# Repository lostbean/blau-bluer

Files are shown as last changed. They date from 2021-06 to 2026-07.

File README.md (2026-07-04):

# blau-bluer

Mods, tuning, slicer profiles, and PCB-making setup for the Two Trees Bluer 3D
printer.

## Firmware

The Marlin firmware lives in its own repo (with its own nix flake for building):
https://github.com/lostbean/Marlin

## PCB making

The printer is adapted to hold a drill spindle and a laser (mounts in
`mods/`). [`PCB/`](PCB/README.md) documents how to make PCBs with it —
marker-drawn etch resist plus drilled holes — including the pcb2gcode configs
and G-code preambles. A laser-based workflow will be added there later.

The alignment-and-drilling half of this now has a browser app,
**[blau-drill](https://github.com/lostbean/blau_drill)**, that replaces the
manual pcb2gcode + touch-off flow: it fits the fiducials, gates the dangerous
moves behind states you have to pass through, and drives the printer directly
over Web Serial. Try it live at <https://onedgy.com/lab/blau-drill/>; the post
[From Ritual to Software](https://onedgy.com/blog/blau-drill/) explains why it is
built the way it is.

## Contents

- `mods/` — printed mod parts (sources in `.scm`, meshes in `.stl`)
- `tuning/` — calibration patterns, test models, and reference docs
- `PCB/` — guide and configs for making PCBs with the drill mod
- `Cura/` — printer definition, material profiles, and project template
- `ICESL/` — IceSL slicer settings

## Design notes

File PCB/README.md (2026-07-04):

# PCB making

Single-sided PCBs on the modified printer, in three stages:

1. **Paint** the whole copper side with a permanent marker / spray as etch
   resist.
2. **Laser** away the resist over everything that should be etched, leaving
   ink only on the traces (mount: [`mods/laser-holder`](../mods)).
3. **Drill** the holes with the 775-motor spindle (mount:
   [`mods/motor-775-holder`](../mods)).

Then etch off-printer (ferric chloride / iron perclorate) and clean the
remaining ink.

> An earlier workflow drew the traces directly with a pen instead of
> painting + lasering. Those files are still here
> (`pen-drawing.cfg`, `preamble.ngc`, `preamble_for_drill.ngc`) but the laser
> flow below is the current one.

> **Drilling now has a browser app.** The manual alignment + pcb2gcode drill
> flow documented below is superseded for the drill pass by
> **[blau-drill](https://github.com/lostbean/blau_drill)**, which fits the
> fiducials into an affine transform (no touch-off `G92`), forces a dry-run
> before the real run, and streams to the printer over Web Serial. Run it at
> <https://onedgy.com/lab/blau-drill/>. The design rationale is written up in
> the post [From Ritual to Software](https://onedgy.com/blog/blau-drill/). The
> configs below are still the reference for the etch/laser pass and the manual
> fallback.

This folder holds the printer-specific pieces — the pcb2gcode config with
tuned feeds and depths, the G-code preamble that handles touch-off and
zeroing, and a post-processor that adapts pcb2gcode's output to this
printer's Marlin.

| File | Purpose |
| --- | --- |
| `drill.cfg` | pcb2gcode config: Excellon → G-code for the drill pass |
| `preamble_laser_drill.ngc` | Touch-off + `G92` zero on a fiducial (no pen→drill offset) |
| `postamble.ngc` | Returns to home |
| `postprocess_drill.py` | Fixes spindle command for Marlin; emits a dry-run + real-drill pair |
| `pen-drawing.cfg` | (legacy) pen pass — fills inverted Gerber with marker lines |
| `preamble.ngc` | (legacy) pen pass — pause, zero, tip-cleaning triangle |
| `preamble_for_drill.ngc` | (legacy) pen→drill offset preamble |

An example KiCad project made with the pen process lives in
[autofascination/living-blinds/PCB](https://github.com/lostbean/autofascination/tree/master/living-blinds/PCB).

## 1. Design (KiCad)

- Put **fiducials on all four corners** of the board, on the copper side you
  drill from (back copper). Use a copper fiducial footprint (e.g.
  `Fiducial:Fiducial_BCu_Cross_1.5mm_Mask2mm`). Corner fiducials are the
  alignment reference — and unlike the board edge, **they survive etching**,
  so you can still register to them after the outline copper is gone.
- Set the **Drill/Place File Origin** onto one of those corner fiducials
  (not the bare corner). That fiducial becomes the drill-file origin and your
  physical touch-off point.
- Export from **File → Fabrication Outputs → Drill Files** with:
  - Format **Excellon**
  - _Use drill/place file origin_
  - _PTH and NPTH in a single file_ (so you get one `*.drl`, not `-PTH`/`-NPTH`)
  - _Use alternate drill mode for oval holes_
  - **Do not** enable _Mirror Y axis_ — pcb2gcode handles the back-side mirror
    itself (`drill-side=back`). Mirroring here would flip the holes out of the
    reachable frame.

  Sanity check the exported `.drl`: coordinates should be small and centred on
  the chosen fiducial (one axis going negative is fine), not large absolute
  page coordinates (e.g. X135, Y−149) — those mean the drill origin was never
  set.

## 2. Generate G-code (pcb2gcode → post-process)

Point the paths at the top of `drill.cfg` at your exported `.drl`, then run
from that folder. The pcb2gcode in current nixpkgs fails to build against
boost 1.87, so pin the 24.05 channel (it ships a working prebuilt binary):

```bash
nix run github:NixOS/nixpkgs/nixos-24.05#pcb2gcode -- --config drill.cfg
python3 postprocess_drill.py board.drl.gcode --speed 255 --hover 0.2
```

That writes two files:

- `board.dryrun.gcode` — **spindle off**, hovers `--hover` mm above the
  touched-off surface at every hole instead of plunging. Run this first to
  confirm registration without cutting.
- `board.drill.gcode` — the real run: spindle on at full power, plunges to
  `zdrill`.

Preview either at [NCViewer](https://ncviewer.com/).

### Why the post-processor is needed

pcb2gcode (`software=custom`) emits spindle control that does **not** work on
this printer's Marlin: a cosmetic standalone `G00 S<speed>` line plus a bare
`M3`. Marlin needs the duty value **on** the `M3` line (`M3 S255`) or the PWM
is never set ([MarlinFirmware/Marlin#8379](https://github.com/MarlinFirmware/Marlin/issues/8379)).
The spindle now shares the **laser PWM hardware**, so it is driven directly by
G-code rather than an external controller. `postprocess_drill.py` rewrites the
spindle command, builds the dry-run variant, and can set the touch-off `G92`
to a fiducial position (`--fiducial`, see below).

Values tuned on this printer — change with care:

- `zdrill=-2.5` (through the board into the sacrificial layer),
  `drill-feed=200`, `zsafe=5`, `zchange=30` (lift for bit changes).
- `software=custom` + `nog81=true` because Marlin has no canned drill cycles.
- `drill-speed=255` = full PWM duty (Marlin `CUTTER_POWER_UNIT=PWM255`).

## 3. Align to the fiducial

The drill file's origin is on a corner fiducial, so the fiducial corresponds
to the origin of the G-code frame. In the simple case (origin fiducial maps
to G-code `(0,0)`), the preamble's plain `G92 X0 Y0 Z0` at touch-off is
correct, and holes on the far side may sit at slightly negative coordinates —
the machine accommodates that after the local `G92`.

If the fiducial you align to maps to a non-zero corner of the hole envelope
(e.g. because of the back-side X mirror), let the post-processor read that
corner from the G-code and bake it into the preamble's `G92` — no CAD lookup:

```bash
python3 postprocess_drill.py board.drl.gcode --fiducial bl   # bl|br|tl|tr
```

`--fiducial bl` sets `G92 X<minX> Y<minY> Z0` (the min-X/min-Y hole-envelope
corner), so touching off there tells Marlin where the fiducial is and every
hole lands relative to it. Pick the corner that the back-side mirror maps your
chosen fiducial to (for a KiCad lower-right fiducial drilled from the back,
that is `bl`). Verify in the post-processor's printed hole-envelope numbers.

## 4. Drill

The generated files include pauses (`M0`) — one at touch-off, and one per bit
size change.

1. Upload `board.dryrun.gcode` and `board.drill.gcode` to the printer
   (OctoPrint recommended).
2. Mount the drill bit. At the first pause, position the bit over the corner
   fiducial and lower Z until it just touches.

   **Energize the motors before the final adjustment.** When the steppers are
   de-energized (idle) and then re-engage, they snap to the nearest full step
   and jump 1–2 mm — enough to ruin alignment. So make the _final_ X/Y nudge
   with the motors already on, using the printer's jog/move control, rather
   than pushing the head by hand and letting it re-engage. Jog each axis a
   little first to make sure every motor is holding, then fine-tune onto the
   fiducial.

3. Resume. The preamble runs `G92` to set the fiducial as the zero reference.
4. **Run the dry run first** (`board.dryrun.gcode`). The bit hovers
   `--hover` mm above every hole so you can confirm the pattern lines up with
   the board. There are still per-bit pauses — just resume through them; you
   are not changing bits during a dry run.
5. If registration is good, run `board.drill.gcode`. It drills every hole,
   pausing at each bit-diameter change so you can swap the bit. **Do not move
   X/Y at the bit-change pauses** — only swap the bit and re-touch Z.

## 5. Etch

Etching happens off-printer: the remaining marker ink is the resist, so etch
the board (ferric chloride / iron perclorate) and clean off the ink
afterwards.

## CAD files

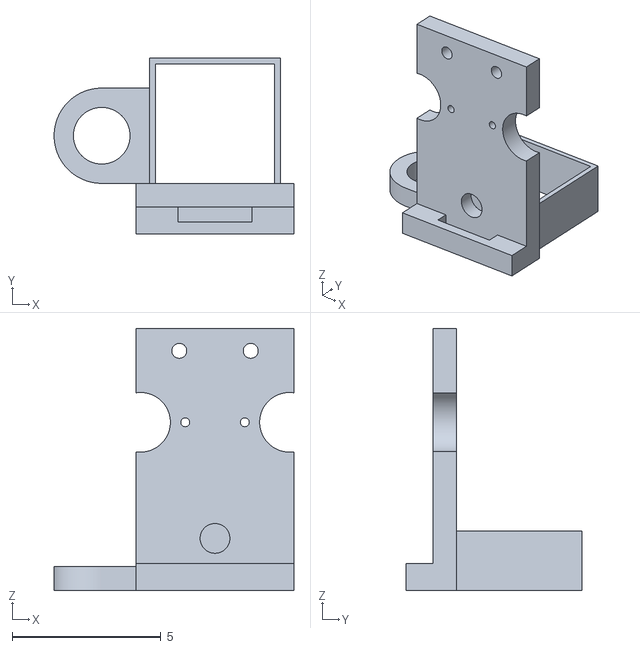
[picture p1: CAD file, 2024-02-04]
mods/laser-holder.stl
8.06 x 5.91 x 8.80

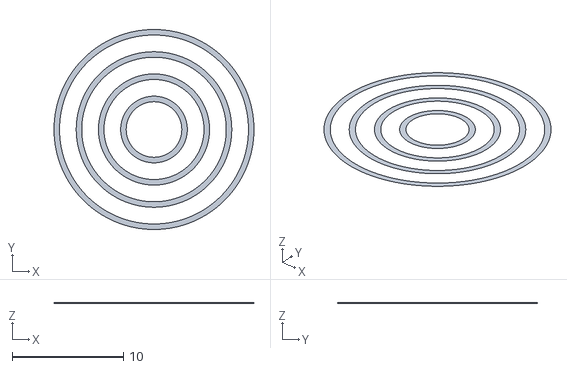
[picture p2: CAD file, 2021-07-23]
tuning/models/bed_level_circles.stl
18.0 x 18.0 x 0.02

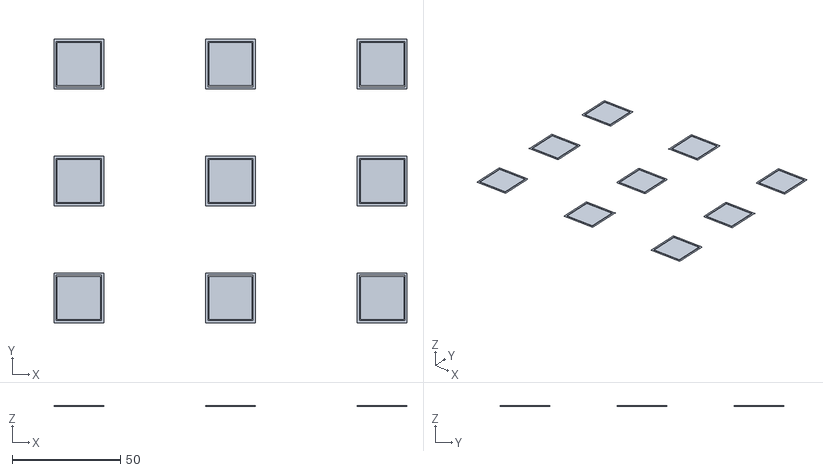
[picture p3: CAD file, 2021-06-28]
tuning/models/Bed_Leveling_Calibration_Test_Object_Parametric/Bed_Levelling.stl
163.0 x 131.0 x 0.1

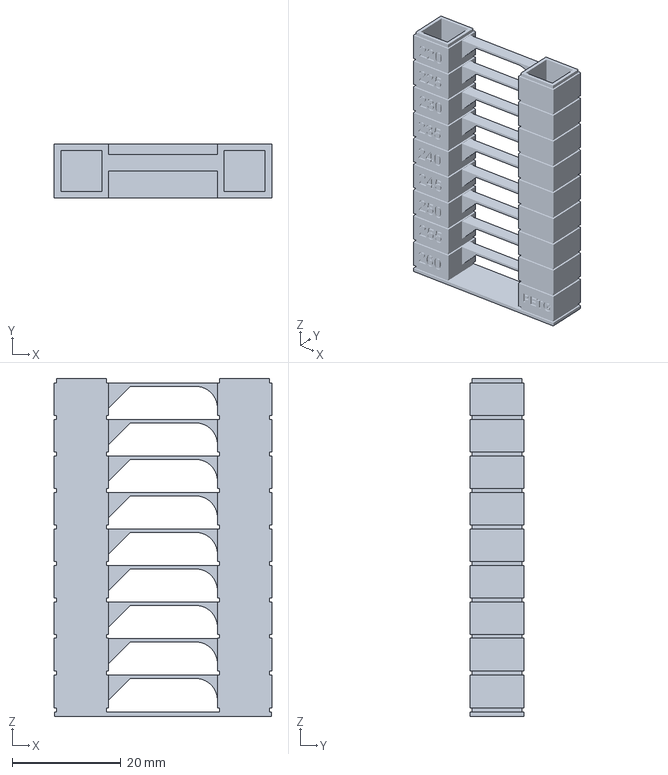
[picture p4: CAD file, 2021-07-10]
tuning/models/TWOTB_220-260PETG_Temp_Tower_.3mf
40.0 x 10.0 x 62.2 mm

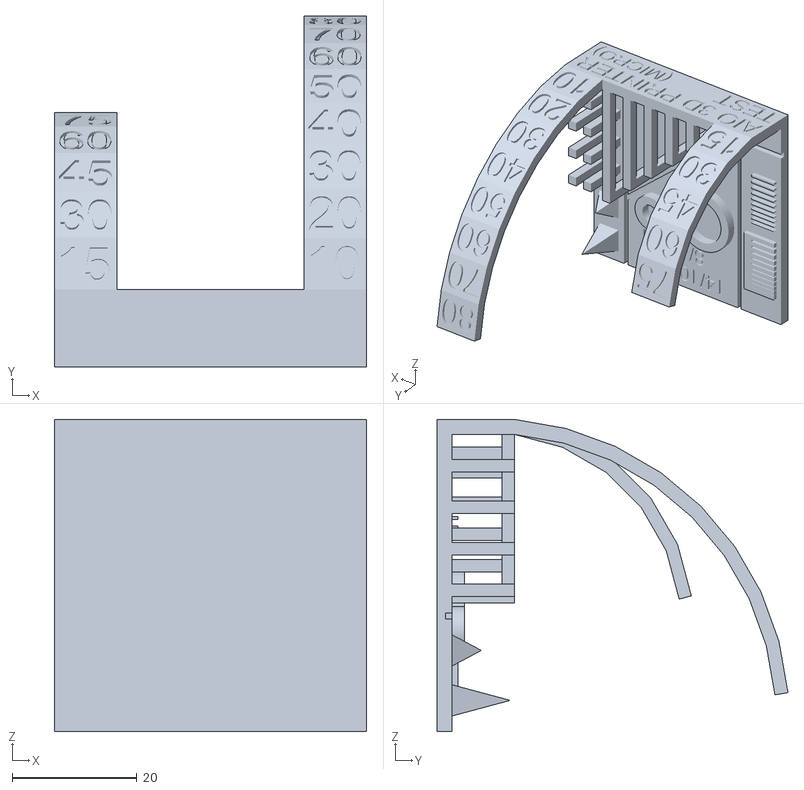
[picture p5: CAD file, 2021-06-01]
tuning/models/All_In_One_3D_printer_test_micro.stl
50.0 x 56.2 x 50.0

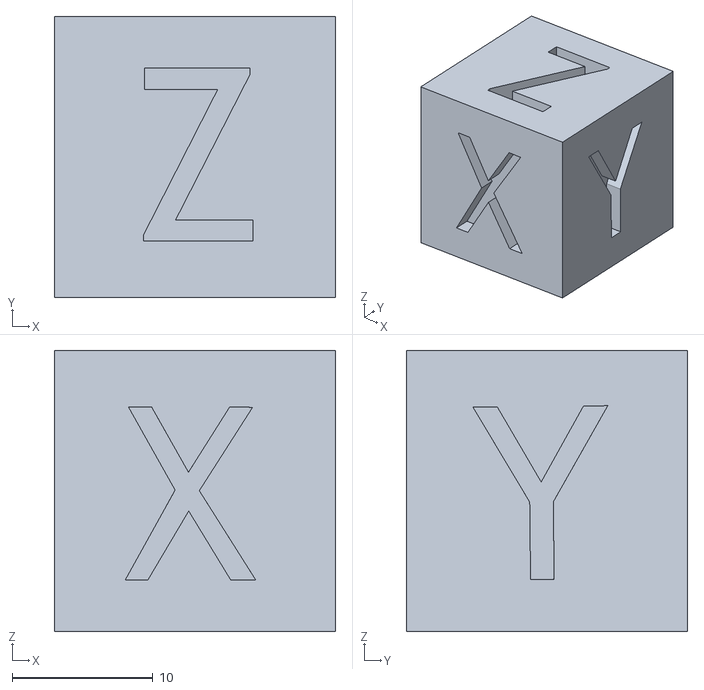
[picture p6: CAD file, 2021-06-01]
tuning/models/xyzCalibration_cube.stl
20.0 x 20.0 x 20.0

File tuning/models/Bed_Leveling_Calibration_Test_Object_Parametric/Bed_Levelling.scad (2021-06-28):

/**
 * Print designed to check that you bed is level
 *
 * print four small squares in each corner to ensure even print quality and good adhesion.
 */

// Define your printers printable area
// If you are using Sprinter firmware then these come directly from configuration.h

X_MAX_LENGTH = 210;
Y_MAX_LENGTH = 178;

THICKNESS = 0.1; //Square / outline thickness
SIZE = 20; //Square width / height
GAP = 0.5; //Width of border between square and parameter
OUTLINE_WIDTH = 1; //Width of parameter around square
OFFSET = 25; //Offset from limits in each axis

translate([OFFSET, OFFSET, 0]) square(); //Top Left
translate([(X_MAX_LENGTH / 2) - (SIZE / 2), OFFSET, 0]) square(); //Top Middle
translate([X_MAX_LENGTH - OFFSET - SIZE, OFFSET, 0]) square(); //Top Right

translate([OFFSET, (Y_MAX_LENGTH / 2) - (SIZE / 2), 0]) square(); //Middle Left
translate([(X_MAX_LENGTH / 2) - (SIZE / 2), (Y_MAX_LENGTH / 2) - (SIZE / 2), 0]) square(); //Middle Middle
translate([X_MAX_LENGTH - OFFSET - SIZE, (Y_MAX_LENGTH / 2) - (SIZE / 2), 0]) square(); //Middle Right

translate([OFFSET, Y_MAX_LENGTH - OFFSET - SIZE, 0]) square(); //Bottom Left
translate([(X_MAX_LENGTH / 2) - (SIZE / 2), Y_MAX_LENGTH - OFFSET - SIZE, 0]) square(); //Bottom Middle
translate([X_MAX_LENGTH - OFFSET - SIZE, Y_MAX_LENGTH - OFFSET - SIZE, 0]) square(); //Bottom Right

module square() {
	//Center square
	translate([
				OUTLINE_WIDTH + GAP,
				OUTLINE_WIDTH + GAP,
				0
			])
		cube([SIZE, SIZE, THICKNESS]);

	//Parameter
	difference() {
		//Outer square
		cube([
				SIZE + (2 * (GAP + OUTLINE_WIDTH)),
				SIZE + (2 * (GAP + OUTLINE_WIDTH)),
				THICKNESS
			]);

		//Inner square
		translate([OUTLINE_WIDTH, OUTLINE_WIDTH, -5])
			cube([SIZE + (2 * GAP), SIZE + (2 * GAP), 10]);
	}
}

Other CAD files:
Cura/project-template/PETG-3DFila.3mf

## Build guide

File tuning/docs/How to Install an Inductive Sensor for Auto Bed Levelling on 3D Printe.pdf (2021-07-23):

store.ideagen.tech

## How to Install an Inductive Sensor for Auto Bed Levelling on 3D Printe

ideagen3D

8-10 minutes

Just acquired an Inductive Sensor for auto bed levelling? It's a good alternative to dynamic probe-style ABLs:

1. It's cheaper.
2. It has no moving parts - never worry about the probe drooping down and crashing into your prints.
3. However, it's only compatible with metallic and (very-thin) plastic beds. On the bright side, the best consumer 3D printer bed currently (in our opinion) happens to be metallic!
4. Instructions and discussions around this has also been scarce and/or abstract, but we're here to change that!

This is a guide focused on the Ender 3 V2, and our 12mm NPN Inductive Sensor. However, instructions should
be easily transferable to other printers and similar probes since we are not using any niche ABL-specific hardware ports! Just look up the disassembly process on your own printer.

### 3D Printed Mounts

Before starting, you should have a printed mount on hand. ideagen3D has designed mounts for the Ender 3/Pro, Ender 3 V2, and Sapphire Plus.

Ender 3/Pro

Ender 3 V2

Sapphire Plus

### Physical Installation

1. Before starting the installation, please ensure that the bed corners as level (as much as possible) with the springs. Take care not to accidentally rotate the bed levelling springs during this process.
2. Turn off the printer and disconnect the PSU.
3. Push the Bed to the back, and unscrew this bolt.

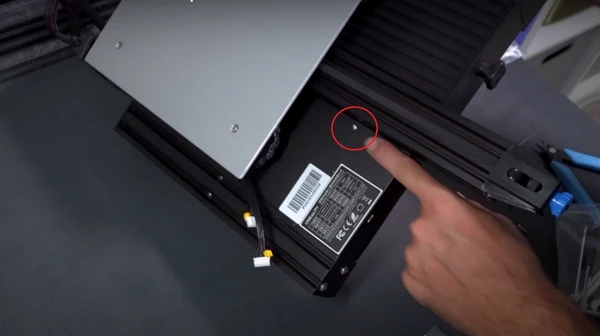
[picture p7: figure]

4. Remove all attachments (e.g.filament spool holder) from the top of the printer, turn the printer upside down and lean it against something.
5. Unscrew these 3 bolts.

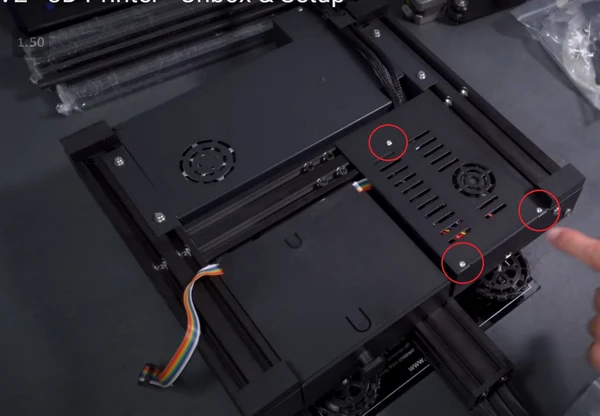
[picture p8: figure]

6. Once inside, disconnect the Zmin stop (check the yellow tag). If you have an upgraded board (e.g. MKS or SKR), it might be preferable to use one of the unused sockets, such as Filament Runout Sensor 2.

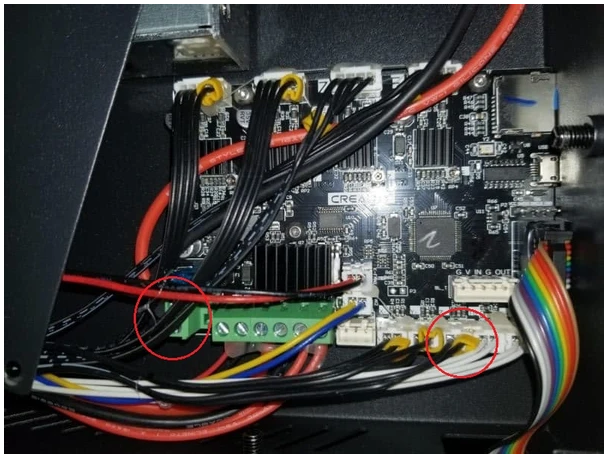
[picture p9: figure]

7. Insert the pre-terminated (black and blue wires) in its place. Polarity does not matter. A dab of hot glue or blue tack may be helpful to hold it in place as this terminal is not self-locking.
8. Now, we need to splice power (12v or 24v) and ground from somewhere. If your board has spare sockets, go ahead and use those. However, the Ender 3 V2 does not, so we will splice into the main 24v power coming in from the PSU.

Loosen the thick red wire from the PSU (red circle on the left, obscured by the black wires on top), and wrap or solder the unterminated (brown) wire around it. It may be helpful to strip a little more of the red jacket so there’s more length to intertwine, but remember to heatshrink/tape back that area to avoid shorting against the metal enclosure.

9. When the wires are in good contact, insert them back into the original hole and tighten back down.
10. Manage the wires to go out the back with the main loom, some zip ties may be helpful.
11. Install the mounting bracket with the provided screws on the unused threads.

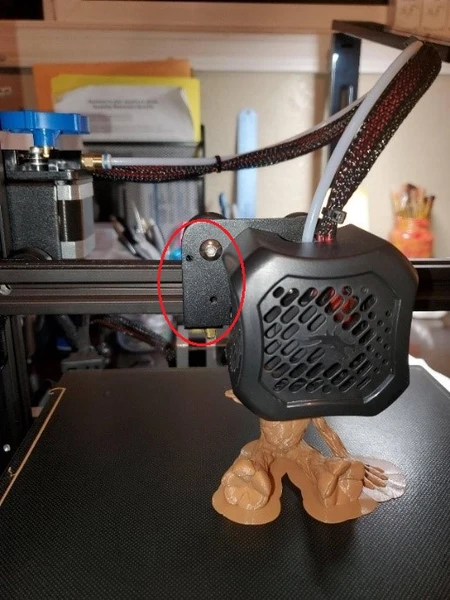
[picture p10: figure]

12. Loosen the nuts on the sensor, and remove the washers. Then, with one nut in place, drop the sensor into the mounting bracket’s hole.

13. The bottom of the sensor should be ~3mm above the nozzle. Adjust this with the top nut, then secure by counter-locking with the other nut from the bottom. We will fine-tune this later.
14. Do some further cable management if necessary.

### Firmware

Here, we will guide you through modifying your firmware to enable support. This guide assumes basic familiarity with modifying and flashing marlin-based firmware. If you are not already familiar with Firmware modifications and flashing, please watch these videos by Michael from Teaching Tech (1, 2), as well as at least a couple videos focused on your specific 3D printer model before proceeding.

ideagen3D customers can contact us for a pre-compiled firmware for printers we carry, assuming no other modifications.

Remember to make a back-up (or a clean base from the manufacturer's website). We are not responsible for any faults or damage caused by improper firmware.

1. Start with a base of Marlin that has been validated to work. Check your printer, mainboard, BAUD rate, etc... are correctly designated.

2. Check/Change these lines in Configuration.h
1. Search "define Z_MIN_PROBE_ENDSTOP_INVERTING" around line 658, and set value to true. This is for NPN probes (that we carry). Leave as false if you have a PNP probe from elsewhere.
2. Search "Z Probe Options", around line 832.
If you have replaced the Z-min probe (as suggested for Ender 3 above), uncomment
#define z_min_probe_uses_z_min_endstop_pin and

#define use_probe_for_z_homing

If you have added the probe into another socket (suggested if you are using an upgrade board, e.g. MKS or SKR), uncomment #define z_min_probe_pin XXX and replace XXX with your selected socket. Consult your mainboard's pinout diagram for this.

3. Search "define FIX_MOUNTED_PROBE" around line 882, and uncomment it.
4. Search "define NOZZLE_TO_PROBE_OFFSET" around line 996, and change your nozzle offset values accordingly (shown here is for the Ender 3 V2 with our printed mount).
#define NOZZLE_TO_PROBE_OFFSET { -43, -1, 0 }

5. Search "define MULTIPLE_PROBING 2" around line 1006

(optional, recommended),
uncomment and verify value of
#define MULTIPLE_PROBING 2

6. And right below, around line 1065, verify these values
#define Z_CLEARANCE_DEPLOY_PROBE 0 // Z Clearance for Deploy/Stow

#define Z_CLEARANCE_BETWEEN_PROBES 10 // Z Clearance between probe points

#define Z_CLEARANCE_MULTI_PROBE 3 // Z Clearance between multiple probes

#define Z_AFTER_PROBING 5 // Z position after probing is done #define Z_PROBE_LOW_POINT -1 // Farthest distance below the trigger-point to go before stopping

// For M851 give a range for adjusting the Z probe offset
#define Z_PROBE_OFFSET_RANGE_MIN -10 #define Z_PROBE_OFFSET_RANGE_MAX 10

// Enable the M48 repeatability test to test probe accuracy #define Z_MIN_PROBE_REPEATABILITY_TEST

7. Search "define AUTO_BED_LEVELING_BILINEAR" around line 1319, and uncomment it.

8. And right below, around line 1328, uncomment
#define RESTORE_LEVELING_AFTER_G28

9. Search for "define GRID_MAX_POINTS_X" around line 1380 Verify that it is uncommented, and set it to your preferred value. As a general rule of thumb, you want one point for every 60mm bed size, and it has to be an odd number so the center gets probed. This translates to 3 for the Ender 3, and 5 for Sapphire Plus.
10. All done! Go ahead and re-compile and flash.

### Calibration

1. Turn on the printer, test the sensor with a metal object (screwdriver, scraper, etc). The LED should be OFF when not detecting anything, and ON when it detects metal. Otherwise stop here and revise your firmware, particularly
"define Z_MIN_PROBE_ENDSTOP_INVERTING".
2. Move the Nozzle/Inductor to approximately above the bed spring at the the front-right corner of the bed (nearest to LCD screen), either manually via Disable Steppers or through movements in the LCD.
3. Leave a piece of paper on the bed at this.
4. Turn on preheating to PLA temperatures (200 nozzle, 60 bed), and use the menu to decrease Z axis. Use finer resolutions as you approach the bottom, because you want to manually stop the very instant you hear the tactile “click” from the z-stop. The Z-stop is no longer electronically connected to the printer, and hence is not functional.
5. Double check with the paper that the nozzle is approximately levelled on the bed (not too far, not physically colliding either, dragging the paper in swift motions should feel some “catch”).
6. Remove the piece of paper.
7. Carefully adjust the mount height of the inductive probe until it the LED *just* turns on. Be careful not to accidentally change Z height of the gantry during these adjustments (by leaning on it etc).

### Slicer G-Code modification

There are 2 options here

1. Level the bed and generate the mesh manually, once, through the LCD, then load it up every time a print starts
2. Fresh levelling and mesh on every print. This takes slightly more time but gives better leveling, especially if the bed is moved between prints.

We prefer option 2 - fresh levelling before every print. Either way, first locate the G-Code settings in CURA.

1. At the top left corner, select Settings > Printer > Manage Printers > Machine Settings
2. On the bottom left, there is Start G-Code
3. Look for the G28 line (should be around halfway).

Click here for Option 1 (level once)

add

M420 S1 Z2 ;Enable ABL using saved mesh

after G28 (on the same line)

Click here for Option 2 (level before every print)

add

G29 ;Fresh ABL

after G28 (on the same line)

New generated G-Code from now on should have ABL before printing. This will not affect old G-Code, such as Creality’s provided test prints or pre-sliced G-Codes downloaded from Thingiverse.

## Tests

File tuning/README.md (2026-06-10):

# Bed Level

==========

## Gross level adjustment

First bed level adjustment should be using a piece of paper and the "Level Bed Corners" option on Marlin. This option will bring the nozzle on top of each spring/screew support.

- Before starting, make sure the nozzle doesn't hit the plate when at Z=0.0 by over-compressing the springs (using the knobs under the plate).
- Start the sequence and on each corner put the paper under the nozzle and, while releasing the srping, keep moving the paper in circular motion.
- Stop when the paper starts to get stuck (very suddle feeling) between the plate and the nozzle.
- Repeat the round at least two more times

## Fine mesh level adjustment

This is a fine refinement of the bed level adjustment. It maps the Z variation at different points over the bed creating a Z variation surface to compesate for flatness distortions on the plate.
This process is similar to the process above using the paper but instaed of adjusting the springs, the nozzle will move a high Z possition (normally 0.2mm) and a menu will allow the to adjust the Z position.

After the procedure, store the settings.

## Z offset adjustment

After the bed level adjustment, the Z offset (the distance between the nozzle and the plate) has also to be adjusted. The correct height of the first layer depends of correct Z offset. The Z offset can be configured on the "Bed Z" option.
A GCODE pattern with 5 single layer squares (four on corners and one on the center) is used to validate the correct Z offset.

## References

https://marlinfw.org/docs/gcode/G029-mbl.html
https://teachingtechyt.github.io/calibration.html#firstlayer
https://help.prusa3d.com/en/article/first-layer-calibration_112364/

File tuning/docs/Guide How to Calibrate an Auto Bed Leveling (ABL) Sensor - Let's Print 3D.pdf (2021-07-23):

# Guide: How to Calibrate an Auto Bed Leveling (ABL) Sensor

Several months ago I wrote an in-depth article on How to Setup Auto Bed Leveling which covered the entire process from start to =nish… at least almost. This was my =rst time using auto bed leveling and I was still testing out various methods to calibrate the sensor, where I decided to leave this for a separate guide. At that point, none of the instructions I had found worked out and print jobs would embed plastic in to the build surface, needing to be replaced several times in the process.

As I was getting tired of buying more Build Tak stickers every other week, I went looking once again and stumbled across a video from 3D Maker Noob that seemed promising. Rather than try to adjust the sensor’s position by hand, he used a series of g-code commands to calibrate it with ease. Go =gure, it took all of 5 minutes and my auto bed leveling sensor was near perfect.

Contents
1. Software
2. Calibrate
Steps
3. Start Script
4. Final Thoughts

Compile Marlin Firmware
without VSCode

How to
Install
Klipper on
the Creality
Cloud WiFi
Box

How to
Install the
Gulfcoast
Robotics
Heated Bed
(Ender 3 / 5)
Home | Posts | About
| | Contact
Home ! | Guides ! | Guide: How to Calibrate an Auto Bed Leveling (ABL) Sensor

October 26, 2018

RECENT POSTS

Most of this guide will just reiterate the information he provides in the video, but several personal observations have been added as well. Once you understand it, auto bed leveling makes perfect sense, but most of the resources found online are either needlessly complicated or just plain wrong.

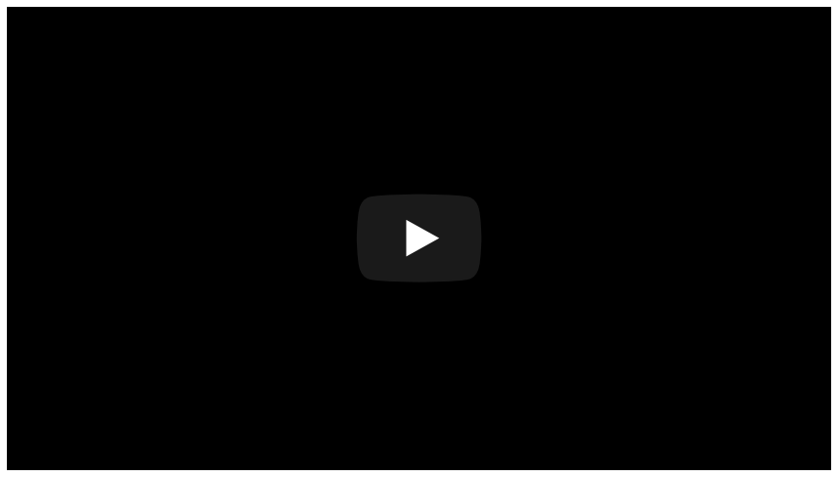
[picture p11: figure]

# Software

Before we can get started, we =rst need to grab some software that can communicate with the 3D Printer over USB. Most slicers have this feature built-in, but Cura seems to be the rare exception that lacks direct machine commands (despite otherwise being a complete printing solution). There are however several other tools I have linked below that will work just =ne for our needs, where I would suggest Pronterface based on the simple, easy to use interface.

Pronterface
Repetier Host

As a third option, Simplify3D ($149) is exceptional software and my preferred slicer software of choice. It is however quite expensive and not worth the price tag for the average person, so unless you already own it, one of the free solutions above will be more than capable of getting the job done.

The 8 Best
Extruder
Upgrades
for Creality
Ender 3
[2021]

Calibrating Z-Offset With A BLTouch Bed Lev…

# Calibrate Steps

Go ahead and connect the 3D Printer to your computer using a USB cable and power it on. Start up Pronterface (or whatever software you decide to use) and connect it to the machine. The Baud Rate will likely be set to the default of 115200 and the COM port will appear when the 3D Printer is connected, such as COM3.

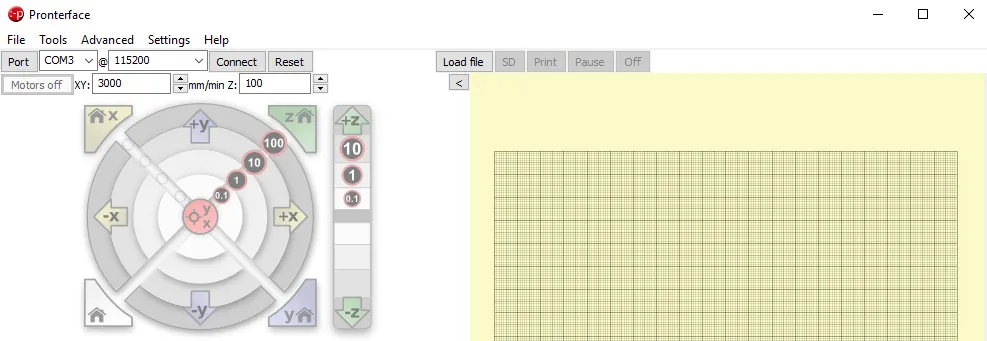
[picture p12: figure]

Now our goal here is to =nd and set the proper Z-Offset for our nozzle, based on the position of the ABL sensor and where it triggers. The Z-Offset is an adjusted value, which raises or lowers the nozzle from the actual home position. So if we run “Auto Home” and the current nozzle position is at 0, a Z-Offset of -0.5mm would bring it closer to the bed.

It’s important to note that the Z-Offset value is not used when the printer auto homes (G28 command) or probes (G29 command) the bed, only during an actual print. This wasn’t documented anywhere and caused quite a bit of initial confusion on my part.

Since there may already be a pre-existing z-offset con=gured in the =rmware or EEPROM, we will start by clearing out any current values and reset the offset to 0.00.

G28 Home the nozzle
M851 Z0 Set the z-offset to zero
M500 Store the settings to EEPROM

! Step 1: Clear the Z-Offset

M501 Load the settings from EEPROM
M851 Echo the current z-offset value, make sure this reports Z0

When the Auto Bed Leveling (ABL) sensor is triggered, the =rmware will raise the nozzle up by several millimeters. Since we want to work from the actual 0 z-offset, we need to re-position it at the point the sensor was triggered. To do this, we will use G1 F60 Z0, where G1 is the move command, F60 is the travel speed, and Z0 is where we are moving to.

G28 Z Home the nozzle on the Z axis
G1 F60 Z0 Move the nozzle down to the actual 0 offset

Just like we are used to with manual bed leveling, go ahead and insert a piece of paper under the nozzle to test the distance. Using the movement controls in the software, start lowering the nozzle towards the build plate in increments of -0.1mm, until there is a slight drag on the paper when sliding it underneath. We will temporarily disable the software endstops, where that will allow us to go in to negative values on the Z axis while we calibrate the proper offset.
Once you are satis=ed with the distance between the nozzle and the bed, make a note of the z-offset on the 3D Printer’s LCD screen, which should look something like “Z-0.5”. Now add the thickness of the paper you used to this value and that is your actual z-offset.

Note: A normal sheet of paper has an average thickness of 0.08mm. If your LCD screen reads Z-0.5, we would con=gure this as Z-0.58.

! Step 2: Move to Actual Z-Offset

! Step 3: Calibrate Z-Offset

M211 S0 Turn OFF the Software Endstops M851 Z-0.58 Set the z-offset value
M211 S1 Turn ON the Software Endstops M500 Store the settings to EEPROM M501 Load the settings from EEPROM

# Start Script

Since we want the 3D Printer to use the auto bed leveling sensor and probe the surface before each print, we need to tell it to do so via the Start script. This is a list of G-code
commands that it executes in order before the print can start. Open your preferred slicer software, locate the Start script and add the G29 probe command to it.

Cura: To access the Start script g-code in Cura, go to the Settings menu -> Printer -> Manage Printers. Select the desired printer in the list and click the Machine Settings button next to it. You will =nd the “Start G-Code” section in the bottom left.

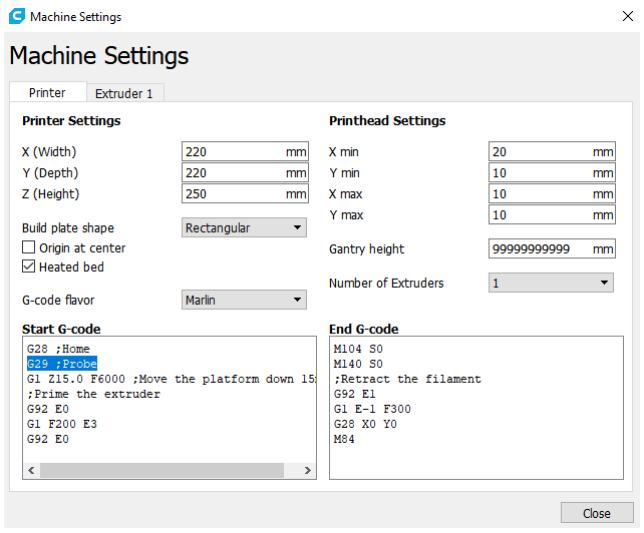
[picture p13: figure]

Simplify3D: To access the Start script in Simplify3D, open the Process Settings -> Scripts tab -> Starting script tab.

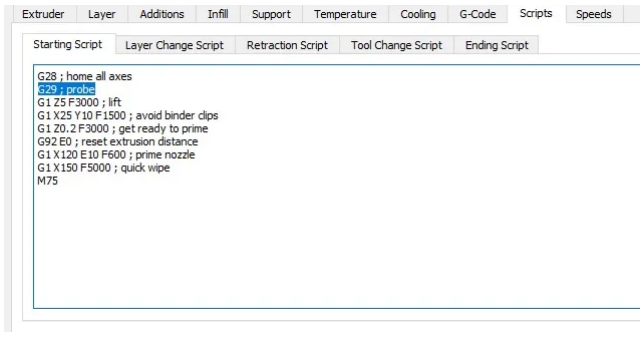
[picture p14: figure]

# Final Thoughts

As I am of the mindset “why =x what isn’t broken”, auto bed leveling always seemed like a solution for a problem that didn’t exist. Sure, it takes a few minutes to level the bed by hand, but I didn’t exactly understand what this feature was capable of. Until it was properly con=gured, it seemed to be a hindrance more so than anything, turning a simple process in to something complex.

Once it was setup and I eventually =gured out how to calibrate the sensor, the bene=ts became much more apparent and it was a luxury I came to appreciate. While it of course reduces the frequency in which leveling is required, the real upside was the fact that it maps out the build surface when probing. In cases where the bed isn’t perfectly iat, it will use the generated mesh data to adapt and work around imperfections in the plate… something that manual bed leveling simply cannot do.

" PREVIOUS ARTICLE

## Guide: How to Install the Micro Swiss All Metal Hotend (Ender-3)

NEXT ARTICLE !

## Guide: How to Upgrade the Extruder (Ender-3)

# 8 thoughts on “Guide: How to Calibrate an Auto Bed Leveling (ABL) Sensor”

Dear Brett,

I have been suffering for days after I upgraded my 3D printer with 3D touch sensor, thanks to your excellent guide, I was able to properly con=gure it =nally! (after tens of failed prints and many frustrations ). I appreciate your kind efforts in making this guide and sharing it with the rest of the planet.
Salute,
IC

# REPLY

Ihsan Cicek
December 14, 2020 at 8:16 pm

Hi Ihsan,

That’s awesome! I’m glad to hear this helped get it sorted out.

You’re de=nitely not the only one that has suffered through this. Despite being relatively knowledgeable with =rmware, con=guring and calibrating bed leveling sensors left me extremely confused. It wasn’t well documented and everything I found online seemed to be wrong. It took a lot of experimenting to =gure out what worked, but that video I linked from Breaks n Makes was a great starting point.

-Brett

# REPLY

Same as Ishan here. Thank you so much Brett !
After a =rmware update (where I just changed the MAX number of points for the ABL mesh), impossible for me to set the Z offset correctly again. I spent my entire evening yesterday trying to =x this, driving me nuts.
In step 3, why do you switch off the Software Endstops (M211) before running the M851 command ?
I understand that M211 is used to prevent motion outside a prede=ned boundary, but M851 is just changing a value in memory, it does not actually move the head. Does the M211 command here really do something ?
-Michel

Brett
December 14, 2020 at 11:24 pm

Michel Saint-Ghislain
January 3, 2021 at 7:05 am

# REPLY

Hi Michael,

I wrote this guide a couple years ago, mostly as a reminder for myself when I have to do it again 🙂 The steps aren’t so fresh on my mind anymore, but the way I wrote that section is a tad confusing.

For the second step “Set the Z-Offset value”, I think this was really meant to encompass all of the instructions above. It’s not just 1) turn off endstop 2) set the value and 3) turn endstop back on. The second step should also be =guring out the desired value as described in the preceding paragraphs. I will look at rewriting that part to make it more clear.

-Brett

# REPLY

I found your guide through a google search, and after checking further your website, I noticed that this guide is not to be seen in the “Posts” section. Maybe is it on purpose as it is older ? Anyway just wanted to let you know.
-Michel

# REPLY

Brett
January 3, 2021 at 5:53 pm

Michel Saint-Ghislain
January 3, 2021 at 8:38 pm

Thank you for this fantastic article.
One question: are you adding these commands to your start-up script, or storing them in the EEPROM from pronterface? My issue is that it doesn’t care at all what is in EEPROM, slices from cura 4.8 never take the stored zaxis settings into account.

Is it calling the eeprom settings after the auto bed leveling commands?

G28 Home the nozzle
M851 Z0 Set the z-offset to zero
M500 Store the settings to EEPROM
M501 Load the settings from EEPROM
M851 Echo the current z-offset value, make sure this reports Z0

# REPLY

Hi Kent,

What control board do you have running on your 3D Printer? Certain models like the SKR Mini E3 V1.2 did not have an on-board EEPROM, where that could potentially explain the issue.

As for those speci=c steps, they are being entered into the live console from Pronterface, where that’s the equivalent of just sending commands directly to the 3D Printer. G28 homes it, then we clear the existing Z offset (just in case to be on the safe side), followed by storing/reloading EEPROM

Kent
March 11, 2021 at 3:54 am

Brett
March 11, 2021 at 8:19 pm to make sure the changes were in fact saved.

-Brett

# REPLY

Brett, Wow man thank you. I tried to get the BL Touch up and running so many times manually. I could not get it to work. Thanks to your guide i just printed the best print yet with a brim that was so consistent that I want to frame it!

# REPLY

# Leave a Reply

Copyright © 2021 Let's Print 3D. All rights reserved. Theme: Cenote by ThemeGrill. Powered by WordPress.

Jeff t jackson
July 6, 2021 at 8:25 pm

Your email address will not be published. Required =elds are marked *

COMMENT

NAME * | EMAIL *

WEBSITE

SAVE MY NAME, EMAIL, AND WEBSITE IN THIS BROWSER FOR THE NEXT TIME I COMMENT.

POST COMMENT

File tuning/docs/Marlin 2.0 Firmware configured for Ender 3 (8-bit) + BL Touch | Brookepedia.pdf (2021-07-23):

# Brookepedia (/p/en)

by Daniel Brooke Peig

## Marlin 2.0 Firmware con1gured for Ender 3 (8-bit) + BL Touch

This is the vanilla version of Marlin Firmware 2.x pre-con2gured for Creality Ender 3 printers with original or generic BL Touch sensors. The standard con2guration 2le from Marlin distribution was carefully reviewed to include the latest Ender 3 speci2c settings from the oAcial Creality 2rmware and from Antclabs.

Please note that this is not the version I recommend for 8-bit boards like the one used in the Ender 3. The most stable and feature rich version of the 2rmware for this architecture is the 1.1.9 that I made available in another article (/p/en/node/136). Marlin 2.x is aimed to a new generation of boards using 32-bit processors, the built in libraries are bigger and there is less space left for features. Anyway, if you want to try this you can be sure I did the best I could to con2gure it properly and 2t the maximum amount of features possible. It was downloaded and installed more than 10000 times and I believe most of the users will 2nd no problems with it.

### Features

OAcial "vanilla "Marlin 2rmware with all hardware settings from Creality latest oAcial 2rmware.

1 year ago | By Daniel (/p/en/user/1) | | | 206 comments
English (https://www.danbp.org/p/en) | Português (https://www.danbp.org/p/pt-br/node)

!

Home " | Engineering (/p/index.php/en/engineering) | Computing (/p/index.php/en/it)
Outdoors (/p/index.php/en/outdoors) | Reviews (/p/index.php/en/reviews)

About (/p/index.php/en/about)

(/p/en)

The maximum amount of Marlin features that I was able to 2t in the small 128KB memory. BLTouch original/generic versions enabled by default. Compatible with BLTouch versions from 1.0 up to 3.x
No need to remove any capacitors from the board
Installs from the PlatformIO IDE that runs in several operating systems
Source code modi2ed to prevent releasing the BLTouch sensor during "beep" events triggered by LCD menus
Thermal runway protection enabled
Does not reset the bed level settings after the G28 (Home) command
Custom menu with maintenance mode, emergency mode and full auto bed leveling sequence (warmup, wait, home, level and then save settings)
Ultra-precise bilinerar bed leveling algorithm with 25 probing points, 3 slow probes per point (takes about 10 minutes to complete)
Run and toggle the bed level and BLTouch tools from LCD menus
Tuned PIDs for faster heating
M503 enabled (reports all printer settings)
Baby steps enabled and con2gured for the stepper driver "Magic Numbers"
Fully compatible with OctoPrint
All changes from the original Marlin con2g 2le were marked with the comment tag "Customized DBP"
Due memory size limitations, the power resume function was disabled as well as the arc support
LCD menus were changed to "slim mode" to save memory space
Optional compiled 2les ready to upload to the board (no con2guration, no compilation, no installation of any tools):
Creality standard board
Creality upgraded boards with TMC silent drivers (like the 1.1.5)

### Note about the bed leveling strategy

There are two ways to perform the automatic bed leveling, the 2rst is before every print and the second is only when necessary. Based on my experience with the Ender 3, it's better to do an extremely precise (slower) bed leveling when necessary than a simpler one before every print. This 2rmware con2guration redects this choice.

If you want to do quick/imprecise bed leveling before every print you will need to recon2gure the 2rmware.

### Requirements

BLTouch installed on pin 27
Z stop switch removed (it can block the Z axis movement)

IMPORTANT! BLTouch tip height must be adjusted according to the oAcial instruction manuals (https://www.antclabs.com/manual). There are different BLTouch sensor clearences and the YouTube videos tips are wrong most of the times
Bootloader installed
Microsoft Visual Studio Code (https://code.visualstudio.com/) if you plan to install from the source code
PlatformIO IDE (https://platformio.org/) extension installed on Visual Code if you plan to install from the source code

### Instructions for installation from the Source Code

1. Download and install Visual Studio Code. (https://code.visualstudio.com/)
2. From Visual Studio Code extension menu, install the PlatformIO IDE. (https://platformio.org/)
3. With all requirements running, unpack this entire Marlin source code downloaded from the link below to a folder.
4. From Visual Studio Code select File->Open folder and select the folder where the platformio.ini 2le is located. Attention! Use the "open folder" command, not the"open 1le".
5. Look for the con-guration.h inside the "Marlin" sub-folder and edit the following con2guration to the relative coordinates of your BLTouch mount to the Nozzle. This does not need to be too precise, the only purpose is avoiding the probe to test outside the bed. The default settings X = -42mm, Y= -5mm and Z=0 are for this mount (https://www.thingiverse.com/thing:3003725):

#define NOZZLE_TO_PROBE_OFFSET { -42, -5, 0 }

o. Save the 2le and then select Terminal->Run Task->Build . It will take a few minutes for the system to download all dependencies and compile the code.
7. If the code compiled properly you will see something like this in the terminal: "=== 1 succeeded in 00:00:30.050 ===".
p. Connect your printer to the computer using the USB cable.
9. Go to the Visual Code menu Terminal->Run Task->Upload .
10. If everything goes well another message like this "=== 1 succeeded in 00:00:55.010 ===" will be printed.

### Installation using the pre-compiled HEX 1le

The pre-compiled 2rmware is also available here. You can simply burn the compiled HEX 2le directly to your Ender3 board without installing the Visual Studio Code or PlataformIO.

To upload the pre-compiled 2rmware you will need the AVRDUDE 6.3 (https://www.nongnu.org/avrdude/) tool. For your convenience I included the Windows version of this tool in the zip 2le that contains the HEX 2rmware but the tool is also shipped with the Arduino IDE and
PlatformIO. The upload command in Windows PowerShell should look like this:

./avrdude -p atmega1284p -c arduino -P COM3 -b 115200 -v -U flash:w:firmware.hex

The serial port is something between COM1 and COM8, depending on where the USB driver is pointing to, and -rmware.hex is the 2le you are uploading. If you are using other operating
system like Linux the port address will be somehting like this /dev/ttyUSB0.

After initializing the board with the new 2rmware don't forget to recon2gure the probe offsets running the following command from any serial terminal. Replace the default offset values in the command (-42, -5, 0) with the ones for your probe mount.

M851 X-42 Y-5 Z0
M500

### Post-installation con1guration

1. Manually pre-level the bed! This is important because the BLTouch has limited max/min detection ranges and the print quality can be affected if the Z-Axis moves too much.
1. Cool down the bed and the nozzle. Heating should have little to no effect on this speci2c procedure.
2. Disable stepper motors using the LCD menu command.
3. Place a credit card on one the bed, the thickness of the card will be used as a reference distance.
4. Turn the Z axis with your hand until the nozzle hits the credit card.
5. Move hot end to several positions of the bed, starting from the 4 corners. For each position, adjust the bed level knobs to keep the nozzle at the credit card thickness distance from the nozzle. This is what you would do in manual calibration but instead of using a paper you will use the card for convenience. The card thickness does not matter because the BLTouch probe will rede2ne the Z reference.
2. Heat the bed to the printing temperature and run the bed level command from the LCD (Motion -> Bed Leveling -> Level bed) or using the G29 gcode or using the Heat and Level command from the custom menu (recommended). Note that the Heat and Level command waits 2 minutes after the bed is hot to allow the mounted surfaces to expand/contract properly.
3. Save the settings using the LCD menu or the M500 gcode (if you used the Heat and Level custom command, they will be automatically saved).
4. Add the following gcode to the startup code of you slicer, right after the line of the G28 command to load the bed level con2guration from the memory before every print:

M420 S1

5. After enabling the bed level, print something large and dat to adjust the Z offset. The nozzle will always be far from the bed until you adjust the offset to a negative value (LCD -> Con2guration -> Probe Z Offset). Don't forget to save the settings after the print to keep the offset in the memory.

### Custom pre-compiled 1rmware versions for different BLTouch mounting brackets

If you have a different bracket for BLTouch and would like me to pre-compile the 2rmware for you please let me know in the comments below. The compiled 2rmware will be available for everyone so I need detailed information about the bracket manufacturer/model or the link to the site hosting the STL 2les.

### Troubleshooting tips

Disable serial port clients before Zashing: If the COM ports are used by any other app, the dashing process will fail. Shutdown Cura, OctoPrint, any other slicer and any other Serial Monitor program like the Arduino IDE before compiling/dahsing the new ROM.
Correct fuse settings: If you are using other software than AVRDUDE to upload the 2rmware make sure you are using the correct fuse settings. Apparently the Creality tutorial has the wrong settings and the board fails to boot afterwards.
Reset the EEPROM: Sometimes the EEPROM memory is not reset during the Marlin redash and this can cause problems. To reset manually use the following G-Codes from any Serial Terminal: M502 followed by M500.
Blank screen after Zashing: You did not dashed the 2rmware properly. Please use AVRDude according to the instructions above and if this does not work you might have to redash the bootloader.
Optiboot bootloader: To compile/dash the 2rmware forcing optiboot support, edit the 2le platformio.ini and replace the lines default_envs = melzi or default_envs
= sanguino_atmega1284p with default_envs = melzi_optiboot . If you dashed your bootloader with Arduino IDE, that uses optiboot by default, you don't need to update this setting, it works perfectly out of the box.
Serial Port Monitor for Windows: This small program (https://github.com/whitestone-no/open-serial-port-monitor) allows you to send/receive GCode to the printer. If the characters look strange you are probably using the wrong baud rate (start with 115200bps).
avrdude: stk500_getsync() attempt 1 of 10: not in sync: Wrong baud rate for the serial port

Version:
Platforms:
File size:

or serial port already in use (OctoPrint, Cura, etc..). Try con2guring the upload rate to 115200bps. If you are using PlatformIO to upload, make sure you are using the correct baud rate for your environment in the platformio.ini 2le.
Recon1gure the BLTouch probe offsets: Use the following command replacing the -42, -5 and 0mm coordinates with the offsets of your actual mount:

M851 X-42 Y-5 Z0
M500

If you have problems compiling the 1rmware...

I can compile the 2rmware for you. Please see here (/p/en/node/152) for more details.

### Other Marlin downloads for Ender 3

Marlin 1.1.9 for Ender 3 (8-bit) with Mesh Bed Leveling (no BLTouch) (/p/en/node/146) Marlin 1.1.9 for Ender 3 (8-bit) with BLTouch (/p/en/node/136)
Ultimate Marlin 2 for Ender 3 (8-bit) + BLTouch (advanced users only) (/p/en/node/143) Marlin 2.x for Ender 3 with SKR Mini E3 v2 boards (/p/en/node/149)

FILES

Marlin 2.0.1 (January/2020)
Any operating system
5.1 MB (source), 450 KB (HEX) Download link
Package 1: Source Code for Ender 3 + BLTouch (https://www.danbp.org/downloads/Marlin-2.0.1.zip)
Package 2: Compiled Marlin (HEX) for Ender 3 + BLTouch (https://www.danbp.org/downloads/Marlin-2.0.1_HEX.zip)
Package 3: Compiled Marlin (HEX) for Ender 3 TMC2208 + BLTouch (https://www.danbp.org/downloads/Marlin-2.0.1_HEX_TMC2208.zip)
Checksum
Package 1 SHA256:
770FA69E3F5A694C41521CBE307EA9B6CC73CCCAE7494669EF93B87D68D0DE9E Package 2 SHA256:
E557C4E5CA17BE436BEE977DA3C864734C66516A0D5608841A6C4DBF47201509 Package 3 SHA256:
96242782112FBE50EE206EA826FBDB38B22DB342D020E83C947109EDEC36B61A

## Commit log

2021-06-01 add reference model xzy cube
    [xyzCalibration_cube.stl]
2021-06-01 add test model
    [All_In_One_3D_printer_test_micro.stl]
2021-06-28 add PETG cura profiles
    [PETG-3DFila.3mf]
2021-06-28 bed level test
    [Bed_Levelling.scad, Bed_Levelling.stl]
2021-07-01 add bed level on PLA
2021-07-04 add Marlin as submodule
2021-07-08 add new bed leveling pattern
2021-07-10 Add PETG bed leveling
2021-07-10 add temp tower for PETG
    [TWOTB_220-260PETG_Temp_Tower_.3mf]
2021-07-22 add Z probe holder
2021-07-23 update firmware with z probe
2021-07-23 Add references to z probe installation
2021-07-23 Add bed level model
    [bed_level_circles.stl]
2021-07-24 Calibrate Z and E
2021-07-25 Add Cura's printer profile with custom start gcode
2024-02-04 add laser and spindle holders
    [laser-holder.stl]
2024-02-05 add STL
2024-02-10 add rpi3a case with cam
2024-02-11 post print adjustments
2024-02-16 update to Marlin LTS 2.1.1
2024-02-17 update with laser
2026-06-10 Remove Marlin submodule and nix dev environment
    The Marlin fork (https://github.com/lostbean/Marlin) now lives as a
    standalone repo with its own nix flake, so the submodule and the
    flake/direnv setup that existed to build it are no longer needed.
    Also drop .vscode and stray junk files (vim swap, .DS_Store).
2026-06-10 Bootstrap nix dev environment
    Nix flake (nixos-26.05) with a devShell providing libfive Studio,
    OpenSCAD, and lefthook; treefmt wired as `nix fmt` (nixfmt, prettier,
    stylua, with ICESL exports excluded from formatting). direnv loads the
    shell via .envrc, and a lefthook pre-commit hook formats staged files.
    Flake inputs use git+https because this network blocks api.github.com,
    which the github: input scheme requires.
2026-06-10 Add PCB-making guide and configs for the drill mod
    Extracted from the experiments in autofascination/living-blinds/PCB:
    pcb2gcode configs for the marker (etch-resist) and drill passes, the
    G-code pre/postambles including the calibrated pen-to-drill offset,
    and a step-by-step guideline README covering design, G-code
    generation, calibration, the two-pass run, and etching. Referenced
    from the top-level README; a laser-based workflow will follow.
    [drill.cfg, pen-drawing.cfg]
2026-06-18 Switch PCB drilling to laser + fiducial workflow
    Document and tool the laser-based PCB process that replaces the pen pass:
    spray/paint resist, laser-ablate, then drill. Add postprocess_drill.py to
    fix the Marlin spindle command (M3 S255) and emit a dry-run/real pair, a
    fiducial-based touch-off preamble, and an updated drill.cfg. Note the
    persistent corner-fiducial and energize-before-adjust alignment tips.
    [drill.cfg]
2026-07-04 Link the blau-drill app and post from the PCB docs
    The drill pass now has a browser app (blau-drill) that replaces the manual
    pcb2gcode + touch-off flow. Point the top README and PCB/README.md at the
    live app (onedgy.com/lab/blau-drill) and the write-up (onedgy.com/blog/blau-drill),
    and note that the pcb2gcode configs remain the reference for the etch/laser
    pass and the manual fallback.
